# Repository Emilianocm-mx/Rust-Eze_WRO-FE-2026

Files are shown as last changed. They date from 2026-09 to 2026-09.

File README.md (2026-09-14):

## 🤖 Rust-eze — WRO 2026 Future Engineers






Official repository of team **Rust-eze** for the WRO 2026 Future Engineers category. Here you will find the source code of our robot, technical documentation, hardware schematics, and multimedia material from our autonomous robot.

---

## 📑 Table of contents

* [👥 Team](#team)
* [📷 Vehicle Photos](#vehicle-photos)
* [⚙️ Mechanical Process](#mechanical)
* [⚡ Electrical System](#electrical)
* [🔋 Power Budget](#Power-Budget)
* [🔌 Wiring Diagram](#wiring)
* [🛠️ Components](#components)
* [💻 Source Code](#source-code)
* [🔧 Build & Setup](#build)
* [💰 Components Cost](#Components-Cost)
* [👕 Team Photos](#team-photos)

---

## 👥 Team

| Name | Role |
|---|---|
| Emi | Mechanical |
| Oliver | Electronics |
| Paco | Programmer |
| Leo | Coach |

---

## 📷 Vehicle Photos

| Front | Front-2 | Right |
|:---:|:---:|:---:|
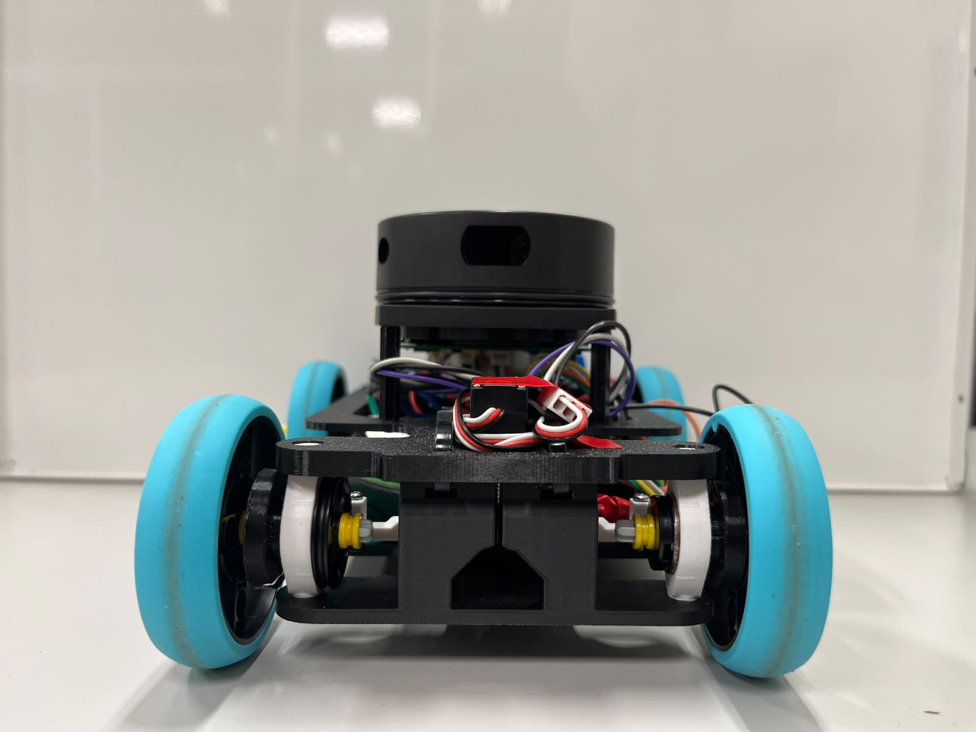
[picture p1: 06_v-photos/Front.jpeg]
Front
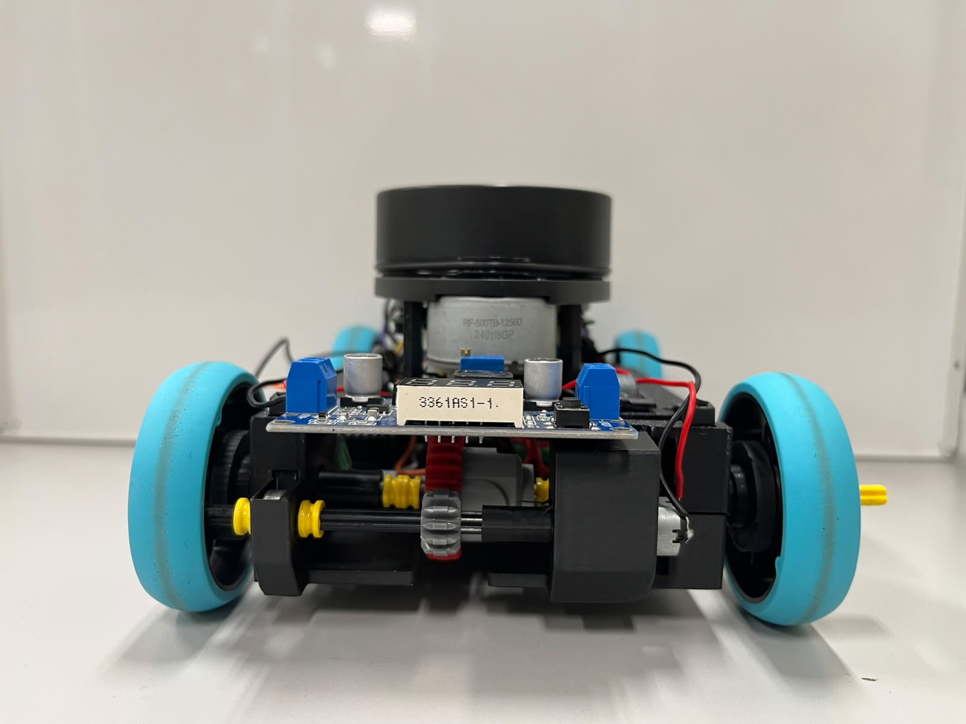
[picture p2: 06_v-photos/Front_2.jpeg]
Front_2
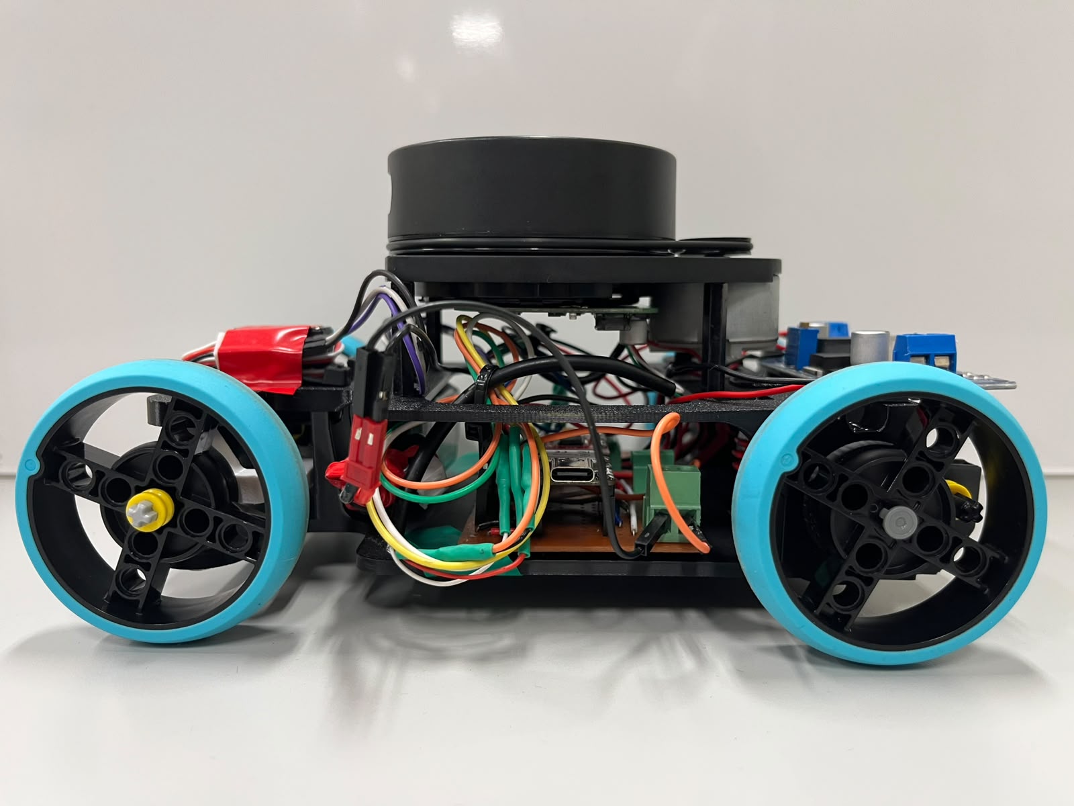
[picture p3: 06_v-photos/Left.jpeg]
Left
|  |  |  |
| **Right-2** | **Top** | **Isometric** |
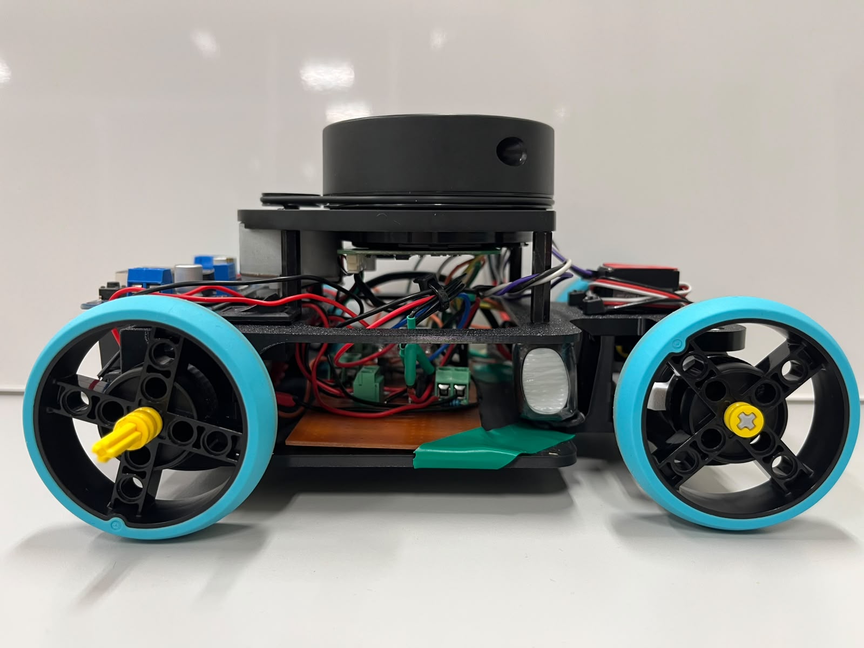
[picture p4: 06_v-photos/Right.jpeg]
Right
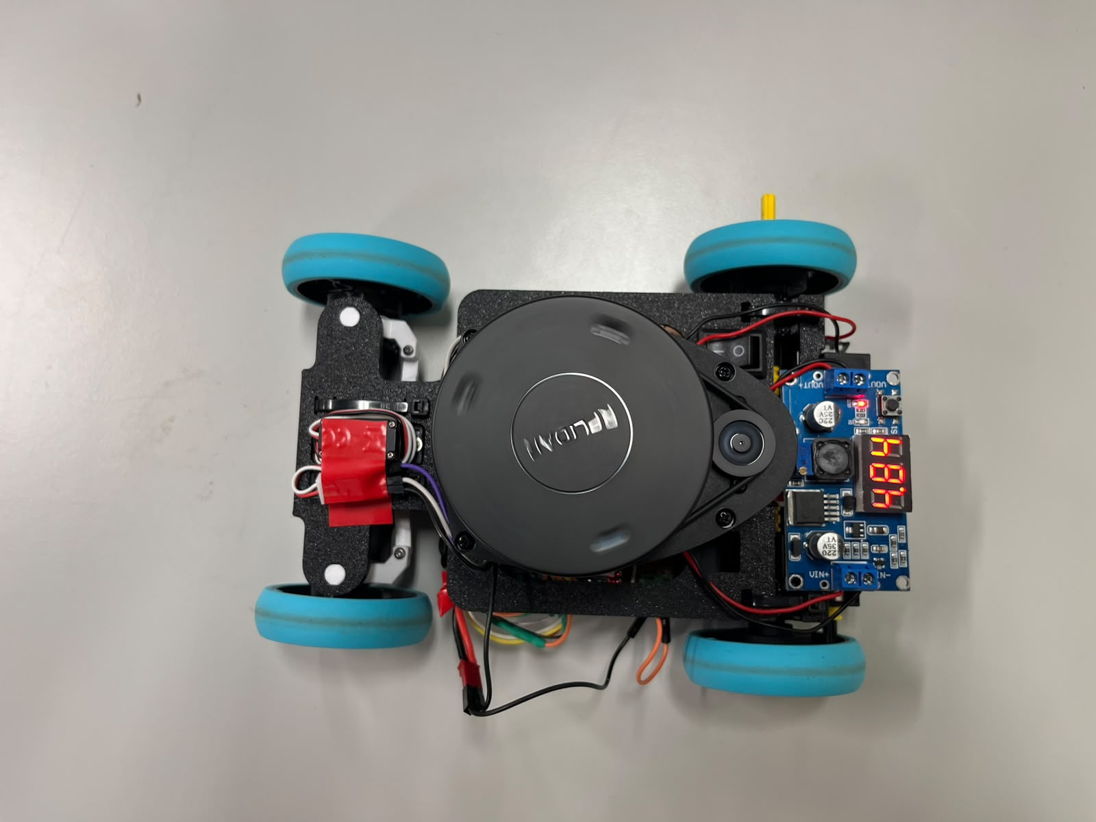
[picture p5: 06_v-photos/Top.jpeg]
Top
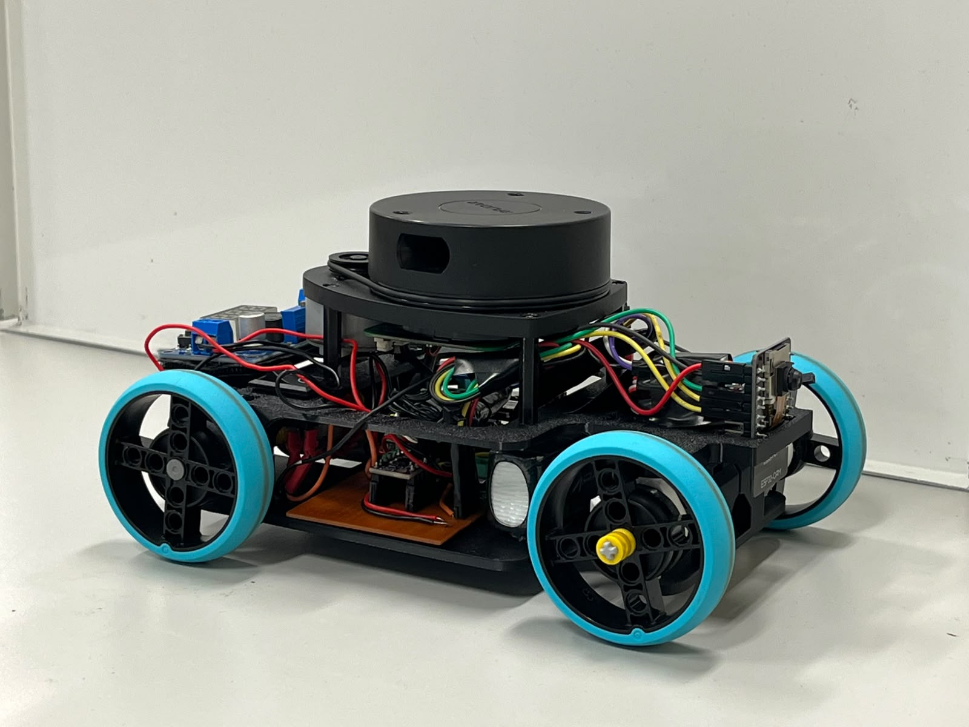
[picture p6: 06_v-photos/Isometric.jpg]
Isometric
|  |  |  |

---

## ⚙️ Mechanical Process

Our mechanical design focuses on stability, and precise maneuverability to tackle the high-speed requirements of the WRO Future Engineers challenges. The entire robot was designed from scratch using CAD software and manufactured via 3D printing. We used SolidWorks as our CAD software:

assy

### 1. Chassis & Weight Distribution
* **Material:** Printed in PLA/PETG for a great balance between rigidity and lightweight performance.
* **Low Center of Gravity:** Heavier components, such as the LiPo battery and the Pololu motor, are mounted as low as possible to prevent the robot from tipping over during sharp corners.
* **Modular Design:** The chassis is divided into easily replaceable sections (front steering assembly, main body, and rear drivetrain) to allow quick repairs during competition days. Also, our CAD desing is basically 2 pieces that consist of a top_cover and main_chassis with each mechanisism working independently.

| Top | Chassis |
|:---:|:---:|
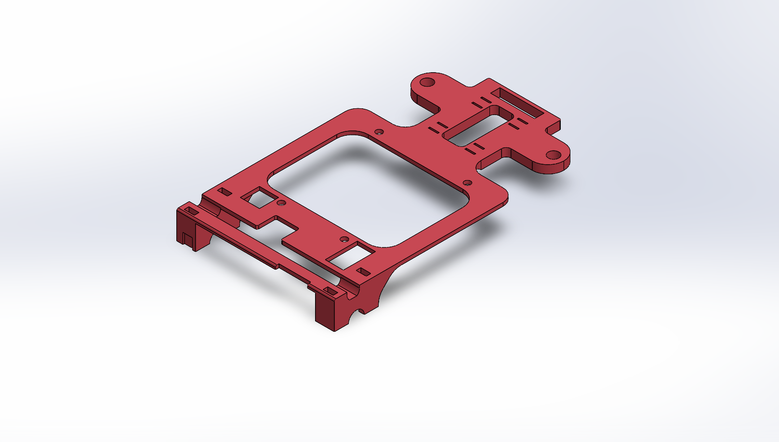
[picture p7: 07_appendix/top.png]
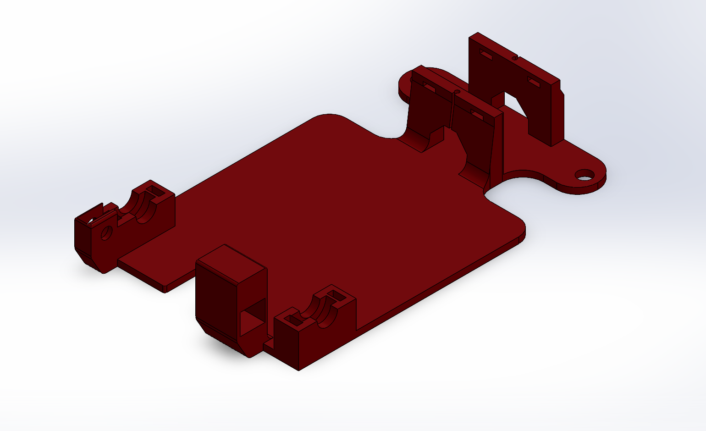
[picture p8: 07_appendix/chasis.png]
|  |  |

### 2. Steering System (Ackermann Geometry)
We used to have a simple paralel steering in our robot, but as we continued with our tests it was clear that the addition of a different type of steering was necessary. To ensure smooth cornering and minimize tire scrubbing, we implemented an **Ackermann steering mechanism** which is the same type that comercial cars use.
* Actuated by the **MG90 Micro Servo** and a steering system assembled with 3 M2 screws ensure that our ackermann the type steering can work efficiently at all times.
* This geometry is critical for maintaining traction and speed while navigating the tight turns of the challenge in general.

| Our Steering | Ackermann Steering Formula |
|:---:|:---:|
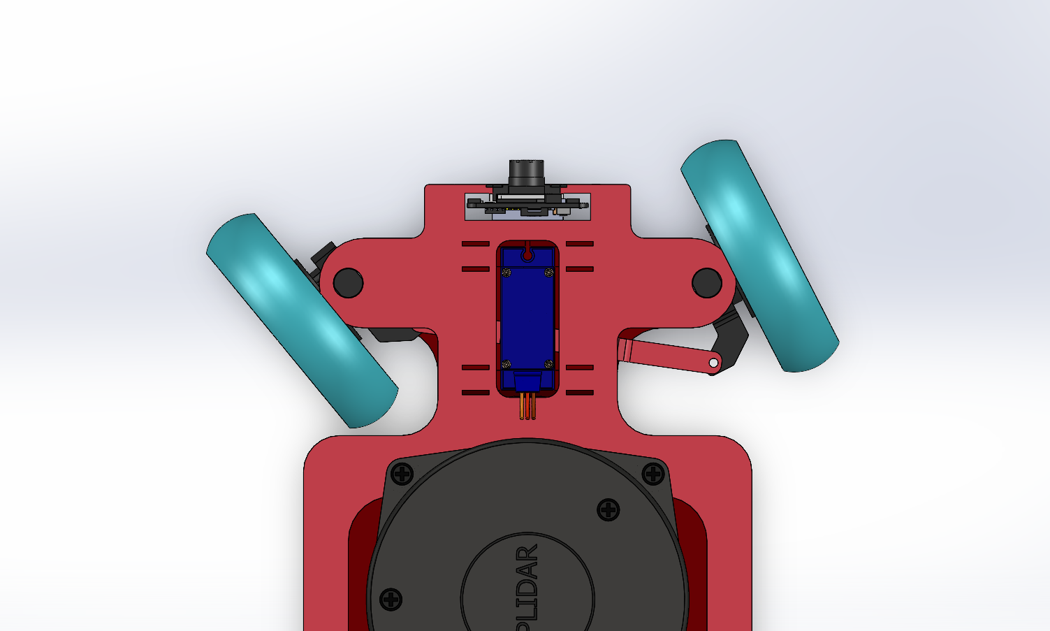
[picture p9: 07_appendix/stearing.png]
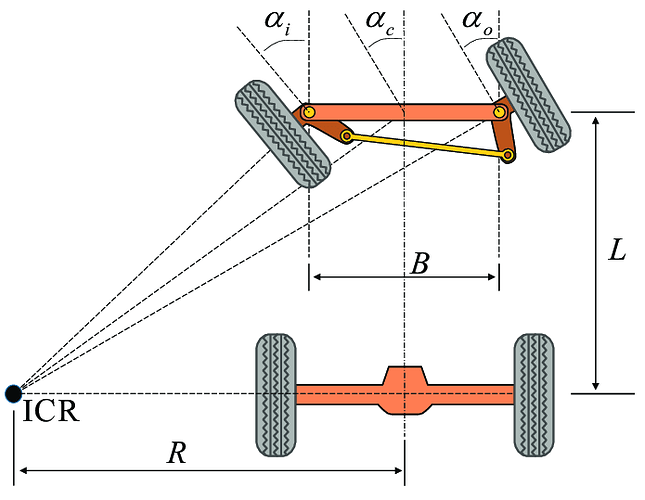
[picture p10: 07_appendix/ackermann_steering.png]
|  |  |

### 3. Drivetrain & Transmission
* **Rear-Wheel Drive (RWD):** Driven by a single **N20 Pololu 300 RPM DC Motor**. While it was not the fist motor we used, the different design itterations helped us find the perfect motor to power out robot. 
* **Power Transfer:** We designed a custom structure with bearings in order to use the lego differential (pieces 65413 and 65414) connecting the motor to the solid rear axle. Originally, the power transfer depended on two single gears of lego (32269 and 32270 being the second one the driver gear), however, this meant a lack of smooth cornering which led us to our new configuration. Our gear ratio was calculated to provide the perfect balance between top speed on the straightaways and high torque for the Obstacle Challenge maneuvers (like parallel parking or the obstacle avoidance). Finally, the design continued to be a mix of 3D printed parts with lego pieces due to the risks that a 3D printed one could have, and since we did not consider necessary to print in stronger materials (like abs or nylon) the legos were a perfect solution to us.

##Transmission & Gear Ratio

| Parameter | Specification |
|---|---|
| Driver gear | 12T |
| Driven gear | 28T |
| **Total Gear Ratio** | **2.33:1** |

For every full rotation of the motor shaft, the differential input rotates 0.43 times. The LEGO new-generation differential distributes torque between both rear wheels with a 1:1 ratio in straight-line motion. During turns, it allows the wheels to rotate at different speeds independently, eliminating tire scrubbing.

** Our torque & performance choices**
* **Mechanical Advantage:** The 2.33:1 gear reduction via the LEGO differential provides adequate torque multiplication for the robot's weight, especially after removing the RPi and powerbank.
* **Overvolting for Performance:** Operating the N20 at 7.4V instead of its 6V nominal rating provides a ~23% increase in both RPM and torque, which compensates for drivetrain friction losses.
* **Electrical Safety:** The TB6612FNG driver operates well within its safe limits with the N20 motor at 7.4V.
* **Weight Optimization:** Migrating from RPi + powerbank to a standalone ESP32 system is estimated to reduce robot weight by 200–250g, improving torque margin from tight to comfortable.

| CAD | Final build |
|:---:|:---:|
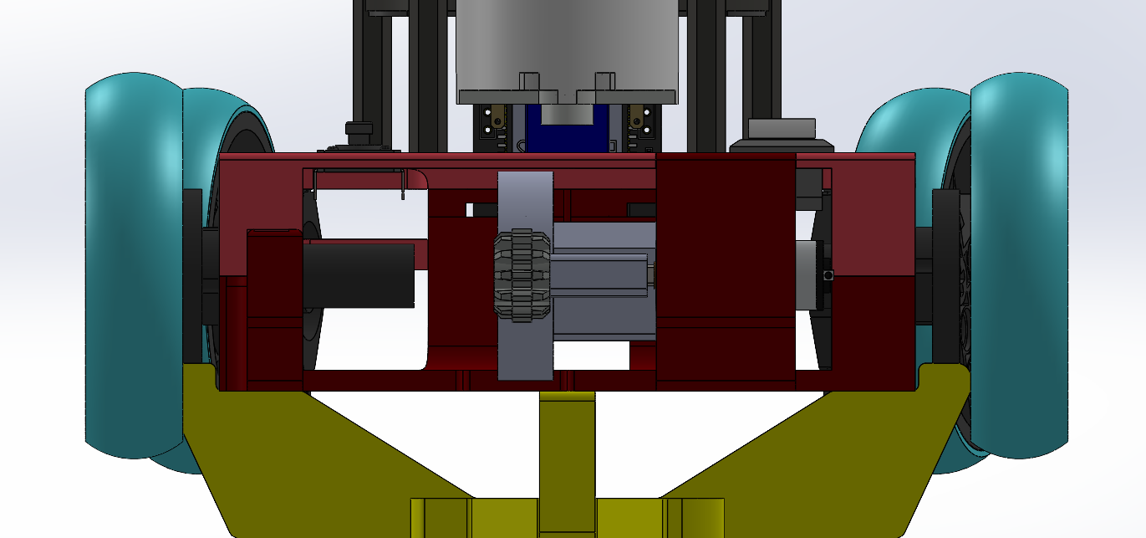
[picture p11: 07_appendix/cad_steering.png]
|  |  |

### 4. Sensor Integration
* **RPLiDAR Tower:** Elevated and centrally mounted to guarantee a 360° unobstructed field of view, preventing any chassis parts from creating blind spots. It is mounted with M2.5 screws with perfectly designed holes in the cassis. It was hard to land with a design that could allow us to fit the electronics without compromising our lidar. Fortunately, the design choice of having to modular pieces was a perfect way of attacking this problem without the appearance of further problems regarding this.
* **Camera Mount:** The ESP32-CAM is mounted in front of the robot with a simple slot on the cassis so that it can still be taken out easily without compromising stability. We consider this a perfect example of our design choices, since we did not had to create a whole assembly in order to mount the camera in the chassis.

| Mounting holes | Final build |
|:---:|:---:|
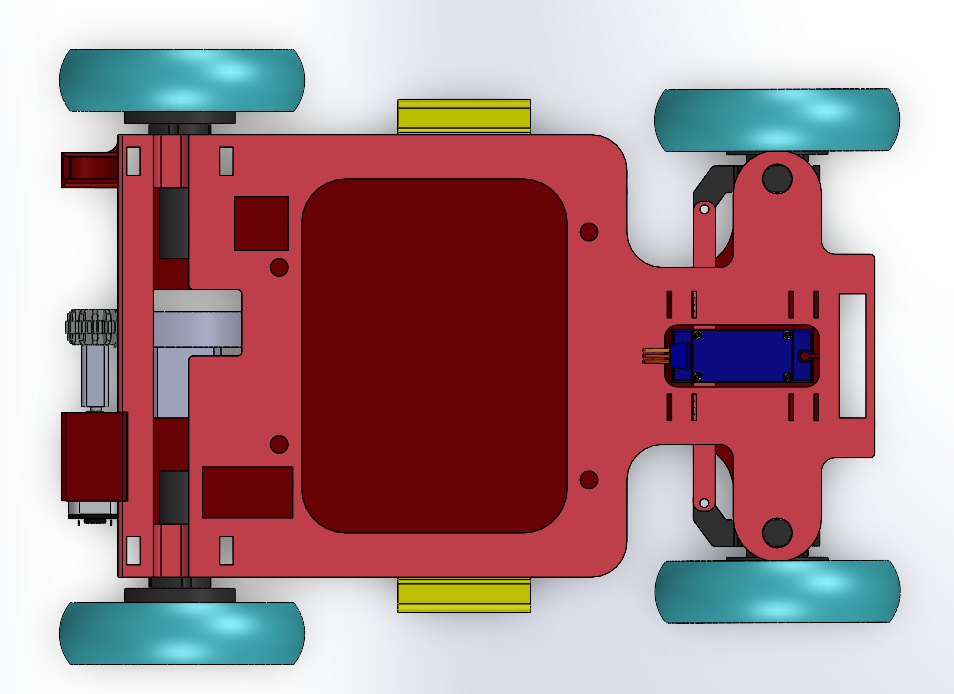
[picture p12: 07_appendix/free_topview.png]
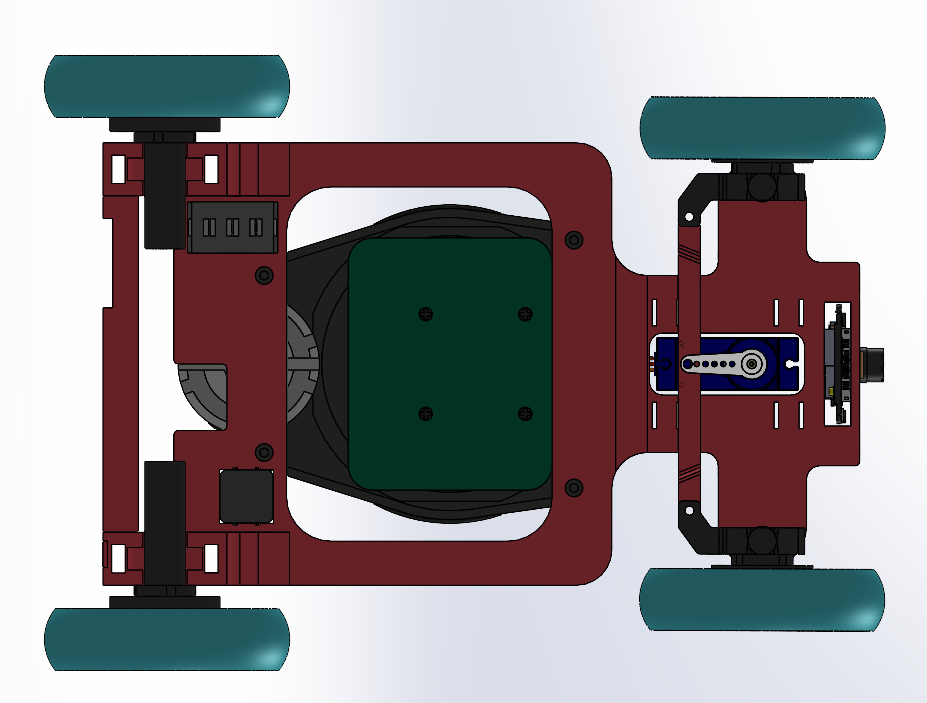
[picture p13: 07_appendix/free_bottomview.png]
|  |  |

### 🔄 Design Iterations

| Version | Focus Area | Key Improvements |
|---|---|---|
| **V1.0** | Functionality and weight reduce | Since we used to depend on a RPI and a PWR BANK, the chassis needed to be light and sturdy in order hold up with the weight of this components. |
| **V2.0** | Steering Optimization | Implemented Ackermann geometry, with a MG90 servo in order to provide more torque for our robot. |
| **V3.0** | Final Frame | We changed to lighter components (XIAO C6 and LiPo battery) so our final chassis ended up being more sturdy and easy to assemble then at the beggining. |

---

## ⚡ Electrical System
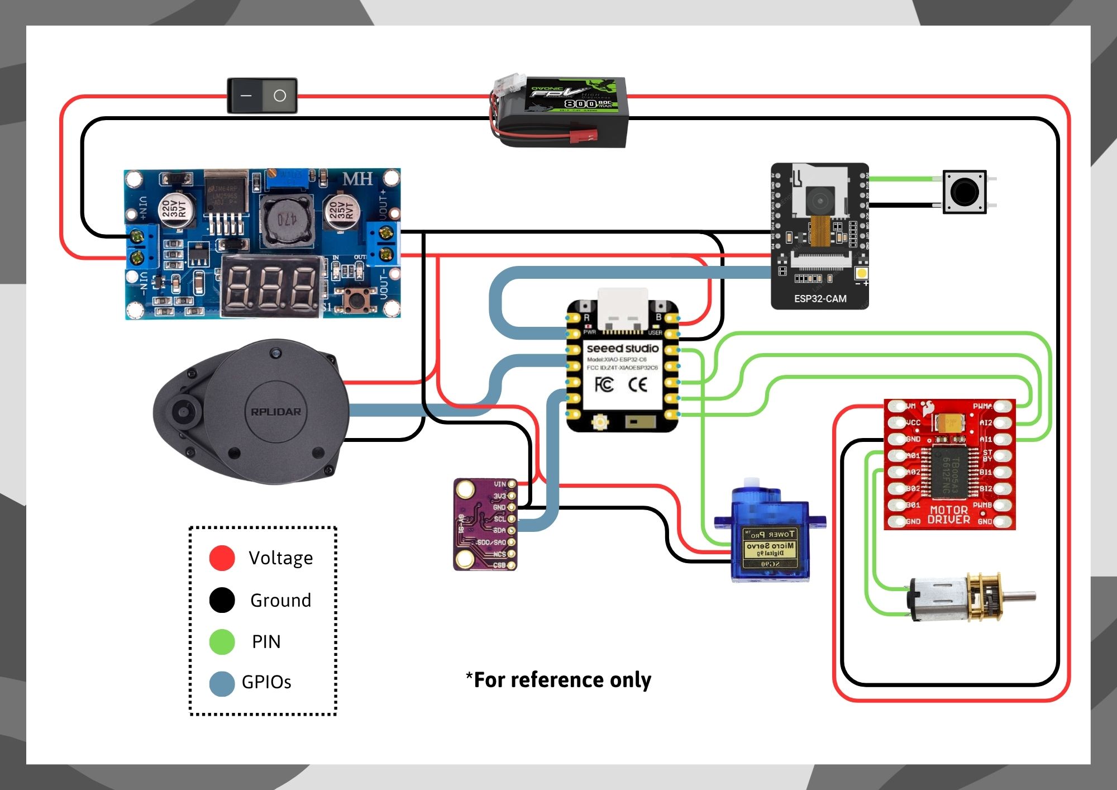
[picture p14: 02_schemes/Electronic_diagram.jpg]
Electronic Scheme


---

### 🔋 Power Budget

The entire vehicle is powered by a 7.4V 800mAh 2S LiPo battery. Power splits into two primary pathways following the main toggle switch (U1): the motor driver takes the 7.4V battery voltage directly to power the DC motor (VM pin), while the rest of the system is fed through an LM2596 step-down converter producing a stable 5V supply at up to 3A.

| Rail | Voltage | Consumers | Estimated Peak Current |
|:---|:---:|:---|:---:|
| Main Power Rail | 7.4V (2S LiPo) | Total system power distribution through Switch (U1) | ~1.85 A |
| 5V Regulated Rail | 5V | LM2596 Converter output -> XIAO ESP32-C6, ESP32-CAM, RPLiDAR A1M8, MG90 Micro Servo, TB6612FNG (VCC logic) | ~1.30 A |
| 7.4V Motor Rail | 7.4V | TB6612FNG Driver (VM) -> Pololu DC Motor (N20) | ~0.50 A |
| 3.3V Logic Rail | 3.3V | GY-BMI160 (IMU) & Push-Button (fed via XIAO ESP32-C6 internal 3.3V regulator) | ~50 mA |

### Battery Selection & Justification

* **Voltage Compatibility:** The 7.4V (2S LiPo) nominal voltage provides optimal operating voltage for the Pololu DC motor without needing a boost converter, while offering enough voltage overhead for the LM2596 buck converter to cleanly step down to 5V.
* **Separation of Power Paths:** Feeding 7.4V directly to the TB6612FNG motor driver (VM) isolates motor stall-current spikes and noise from the 5V logic rail. This prevents brownouts and reboots on the XIAO ESP32-C6, ESP32-CAM, and RPLiDAR A1M8 during sudden motor acceleration.
* **Discharge Headroom:** Standard 800mAh 2S LiPo batteries feature continuous discharge ratings of at least 20C (16 A continuous output). With a total system peak draw of ~1.85 A, the vehicle draws under 12% of the battery's maximum discharge capability, protecting the cells from overheating and voltage drop.
* **Weight & Operating Time:** At a typical average draw of 600–800 mA during autonomous navigation, the 800mAh capacity provides around 45 to 60 minutes of runtime while maintaining a low overall vehicle mass.

---

## 🔌 Wiring Diagram
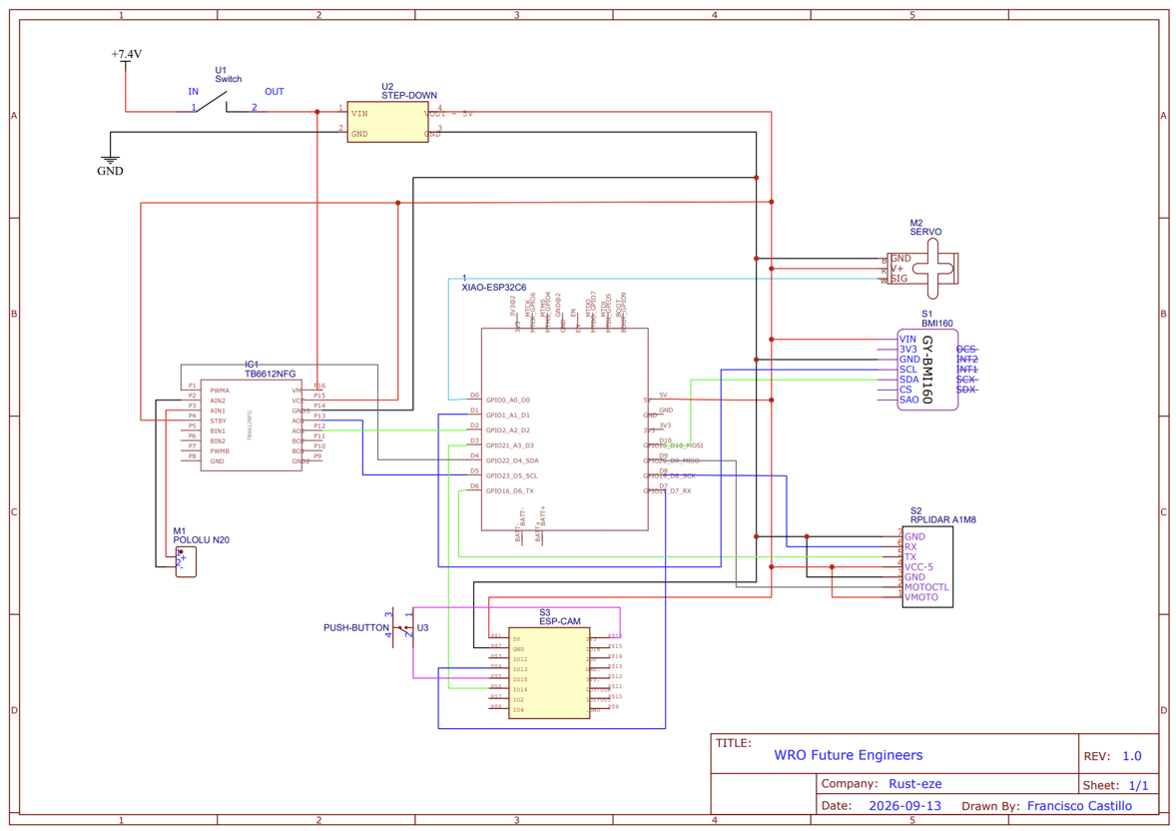
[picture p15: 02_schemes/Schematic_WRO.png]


### Pin Reference

| Component | ESP32-C6 Pin | Function |
|---|---|---|
| LiDAR RX | GPIO 19 | UART data from LiDAR |
| LiDAR TX | GPIO 16 | UART data to LiDAR |
| LiDAR motor | GPIO 20 | PWM speed control |
| Servo MG90 | GPIO 0 | Steering PWM |
| Motor PWMA | GPIO 22 | Drive motor speed |
| Motor AIN1 | GPIO 23 | Drive motor direction A |
| Motor AIN2 | GPIO 2 | Drive motor direction B |
| ESP32-CAM RX | GPIO 21 | UART from camera |
| ESP32-CAM TX | GPIO 17 | UART to camera |
| IMU SDA | GPIO 18 | I2C data (BMI160) |
| IMU SCL | GPIO 1 | I2C clock (BMI160) |

---

## 🛠️ Components

| Photo | Component | Description |
|:---:|---|---|
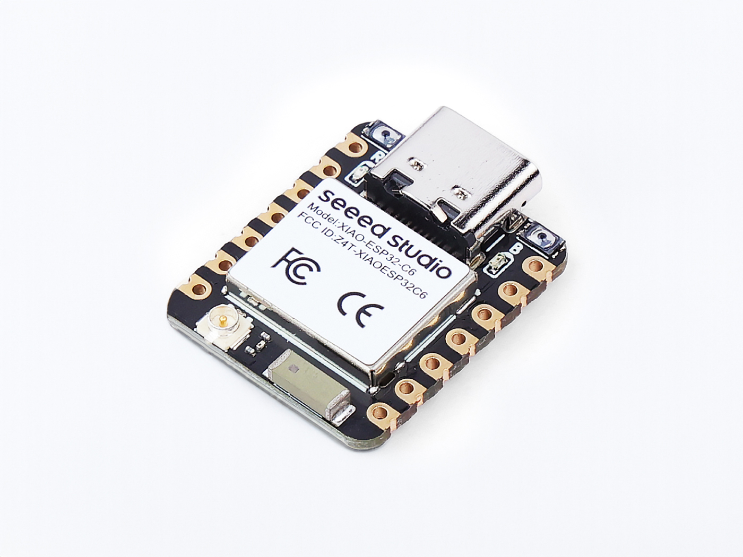
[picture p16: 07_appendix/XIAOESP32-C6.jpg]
|  | **XIAO ESP32-C6** | • Main microcontroller of the robot <br> • Processes RPLiDAR distance data <br> • Controls steering servo and motor driver <br> • Communicates with ESP32-CAM via UART <br> • Runs navigation and PID control logic |
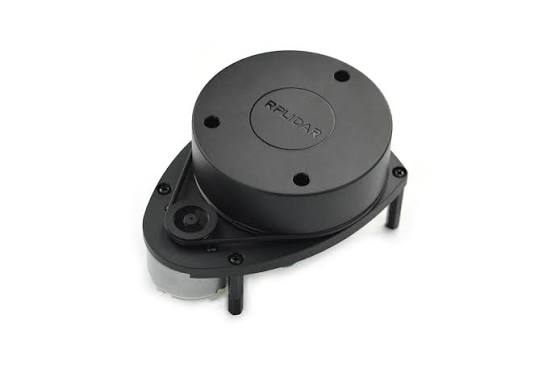
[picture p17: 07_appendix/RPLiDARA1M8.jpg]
|  | **RPLiDAR A1M8** | • 360° laser distance scanner <br> • Primary perception sensor for wall following <br> • Detects corners, open spaces and obstacles <br> • Connected to ESP32-C6 via UART (TX/RX) <br> • Powered at 5V from LM2596 |
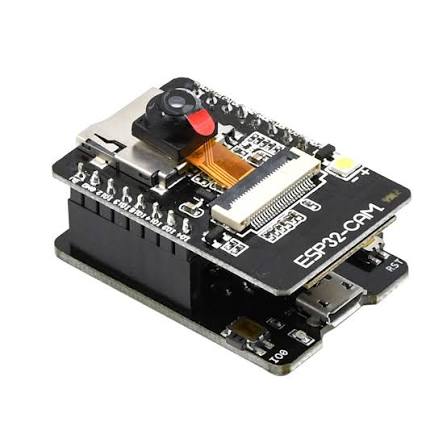
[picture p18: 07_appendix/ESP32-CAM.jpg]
|  | **ESP32-CAM** | • Handles visual color detection <br> • Identifies red and green traffic sign pillars <br> • Sends color decisions to ESP32-C6 via UART <br> • Used to initialize the code with the button |
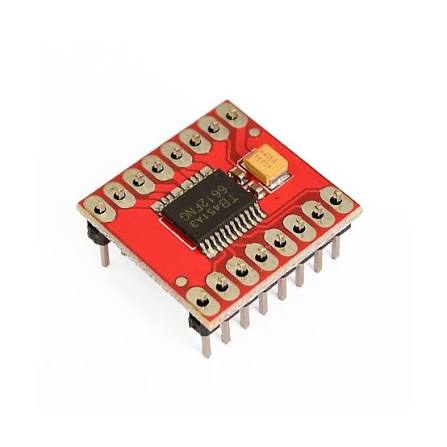
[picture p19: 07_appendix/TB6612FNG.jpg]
|  | **TB6612FNG Motor Driver** | • Controls Pololu DC motor speed and direction <br> • Accepts PWM + direction signals from ESP32-C6 <br> • Powered directly from LiPo at 7.4V <br> • Protects ESP32 from motor current draw |
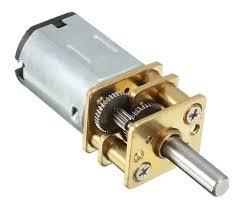
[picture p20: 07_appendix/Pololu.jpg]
|  | **Pololu DC Motor 300 RPM** | • Rear-wheel drive traction motor <br> • Connected to rear axle through physical gear system <br> • Speed controlled via PWM through TB6612FNG <br> • Single motor drives both rear wheels |
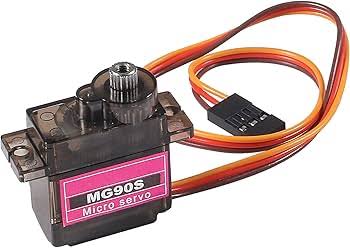
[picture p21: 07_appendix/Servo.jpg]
|  | **MG90 Micro Servo** | • Controls front steering mechanism <br> • Physical range: 40° (full left) to 140° (full right) <br> • Center position at 90° = straight ahead <br> • PWM signal from ESP32-C6 GPIO 0 |
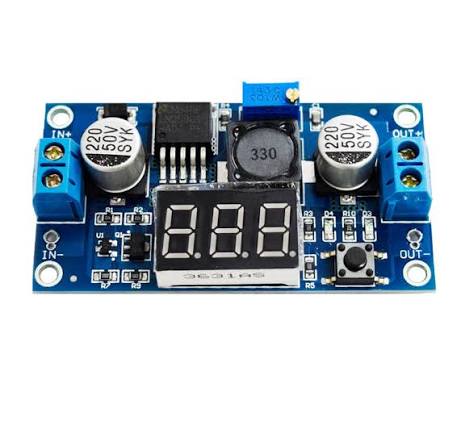
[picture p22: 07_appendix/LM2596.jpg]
|  | **LM2596 Step-Down Regulator** | • Converts 7.4V LiPo down to stable 5V <br> • Powers all logic components safely <br> • Prevents voltage damage to ESP32 and LiDAR <br> • Adjustable output verified before use |
|  | **LiPo Battery 7.4V 800mAh** | • Main power source for the entire system <br> • Directly feeds motor driver at full voltage <br> • Feeds LM2596 for 5V logic rail <br> • Lightweight for weight-sensitive robot design |
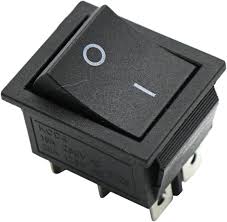
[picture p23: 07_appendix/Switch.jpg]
|  | **Power Switch** | • Master on/off switch for the entire system <br> • Required by WRO rules (one switch to power on) <br> • Cuts all power from battery before start |
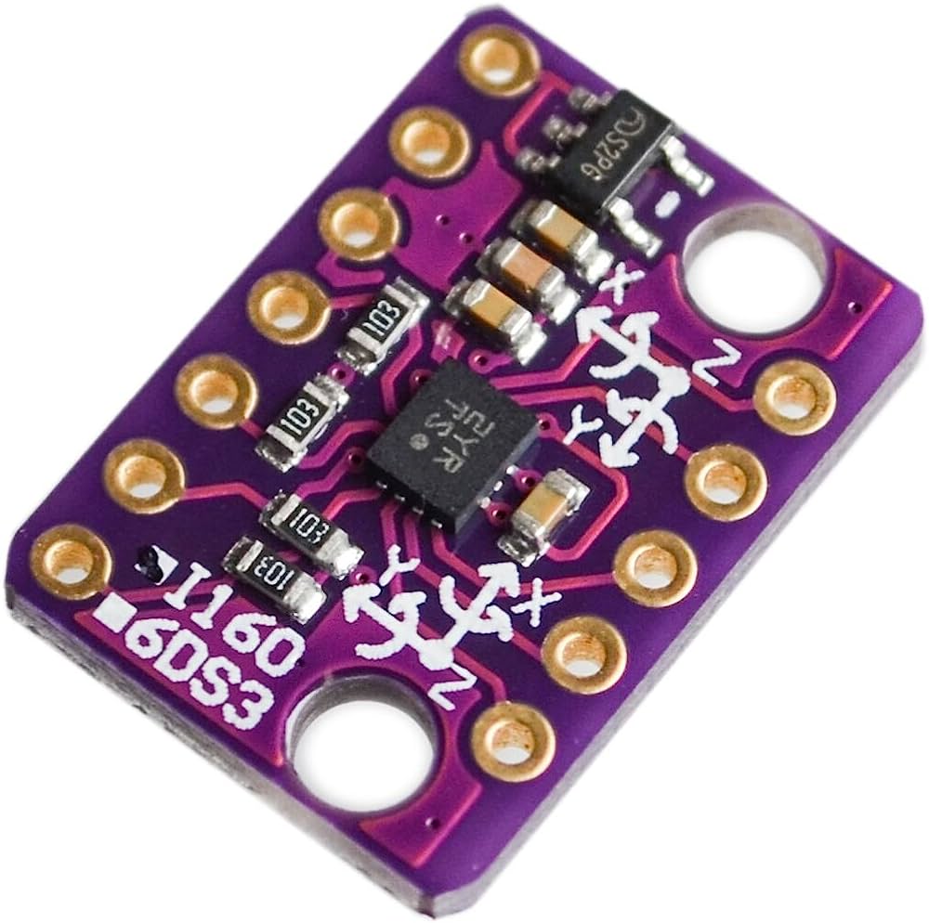
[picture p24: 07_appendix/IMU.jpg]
|  | **BMI160** | • Inertial measurement unit <br> • Provides heading and orientation data <br> • Supports navigation during turns <br> • Connected via I2C (SDA/SCL) to ESP32-C6 |

---

## 💻 Source Code

The main program runs on the **XIAO ESP32-C6**, which processes RPLiDAR distance data in real time, fuses it with IMU heading data, and controls both the steering servo and drive motor through a hybrid PID + yaw control system.

We would like to include more images but since the lidar does not map due to the way our code works the only images that we can provide come from the esp-cam.

---

### System Capabilities

- Reads 360° distance data from the RPLiDAR A1M8 via UART, sampling specific angles as named rays (0°, 60°, 90°, 120°, 170°, 180°, 190°, 240°, 270°, 300°, 340°, 20°)
- Integrates gyroscope data from the BMI160 at 100 Hz to track heading (yaw) with automatic bias calibration at startup
- Runs a **hybrid steering controller**: IMU-based yaw control as primary, with LiDAR wall-following as fallback when IMU is invalid
- Maintains a dynamic wall distance setpoint that is captured fresh after each corner, adapting to each corridor without forcing a fixed target
- Detects corners using a multi-condition state machine: front wall blocked + back clear + lateral opening confirmed + opposite wall closed
- Counts completed corners and laps, stopping the motor autonomously after 3 laps (12 corners total)
- Applies **IMU drift correction** continuously during straight sections by comparing wall angle against integrated yaw
- Receives red/green pillar color data from ESP32-CAM via UART with CRC-validated framing (Obstacle Challenge)
- Implements a **two-device start protocol**: the robot waits for a button press signal from the ESP32-CAM before enabling motion, satisfying WRO's one-button start rule without a physical button on the main controller

---

### 🏁 Open Challenge

The Open Challenge uses the RPLiDAR as the primary perception source and the BMI160 as the heading reference. No camera input is used.

**Startup sequence:**
The robot initializes the BMI160, collects 500 gyroscope samples to compute a Z-axis bias offset, then starts the LiDAR and waits for the start signal from the ESP32-CAM button. Once received, it waits 500 ms before enabling motion, giving the LiDAR rotor time to reach full speed and the IMU reference to settle.

**First corridor:**
Before the first corner is completed, `trackDir` is `UNKNOWN`. The robot reads two diagonal rays on each side (60°/120° for right, 300°/240° for left) and selects whichever wall is closer as its reference. It then follows that wall at the measured distance, using parallelism between the front and back rays to stay aligned. A soft-escape maneuver activates if the robot starts too close to a wall, gently steering away until a safe clearance is reached.

**Straight-line control:**
Once a reference wall is selected, the steering loop runs every 20 ms. It computes a desired yaw correction from the wall distance error, rate-limits the setpoint change to avoid sharp inputs, then feeds it into a yaw P+D controller using the IMU. The derivative term damps oscillation using the live gyroscope rate rather than a numerical derivative. While the IMU is valid, this loop runs as primary. If the IMU fails or loses calibration, the system falls back to a pure LiDAR PID on the wall rays directly.

**Drift correction:**
On every straight section, the system compares the geometric angle of the tracked wall (computed from the two diagonal rays) against the IMU's relative yaw. If they differ consistently, a slow integrating correction is applied to `yawOffset`, keeping the IMU reference aligned with reality over time without introducing sudden jumps.

**Corner detection:**
A corner is triggered when all of the following are true simultaneously: a front wall is detected below 1200 mm, the back is clear beyond 1500 mm, the lateral opening on the turn side has been continuously open for at least 100 ms after previously seeing a wall, and the opposite wall confirms a corridor is closed. This multi-condition approach prevents false triggers from partial LiDAR returns or transient reflections.

**Turn execution:**
When a corner is confirmed, the servo goes to full lock and the IMU target is updated by ±90°. The turn completes when the IMU error falls within 4° and the angular rate drops below 35°/s for 60 ms. A 1400 ms timeout serves as a safety fallback. After the turn, the wall distance setpoint is re-captured from the new corridor's diagonal rays, and all PID state (integral, error smoother) is reset to avoid impulse artifacts.

**Lap completion:**
After 12 corners (3 laps × 4 corners), the robot enters `FINAL_APPROACH` state, drives forward for a calibrated time window (currently 800 ms), then cuts the motor and centers the servo, stopping autonomously in the finish section.

---

### 🚧 Obstacle Challenge

🚧 Obstacle Challenge
The Obstacle Challenge software relies on a tightly coupled sensor fusion architecture running on the XIAO ESP32-C6. Rather than executing hardcoded routines, the robot operates on a reactive state machine that dynamically calculates trajectories based on real-time LiDAR point clouds, IMU gyroscope integration, and ESP32-CAM visual data.

| Red obstacle | Green obstacle |
|:---:|:---:|
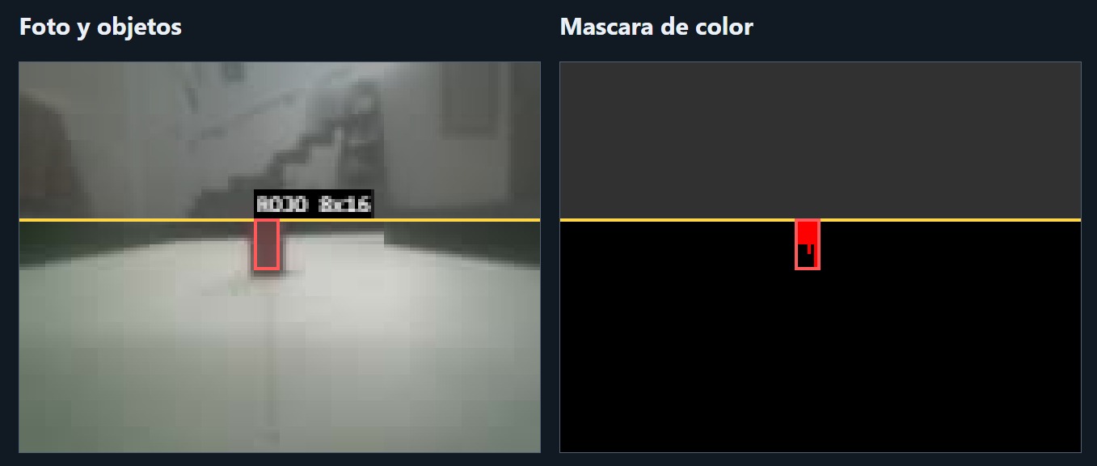
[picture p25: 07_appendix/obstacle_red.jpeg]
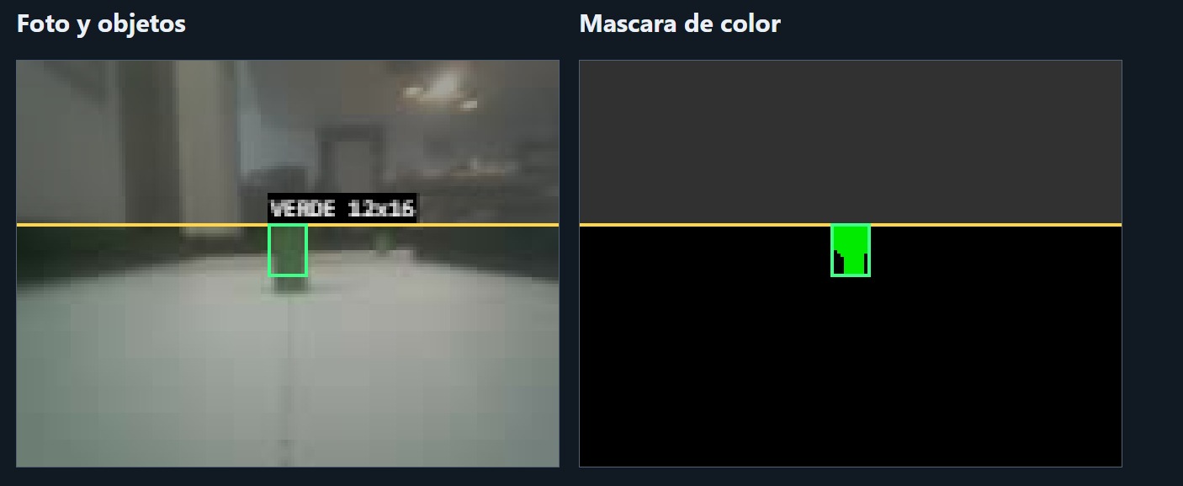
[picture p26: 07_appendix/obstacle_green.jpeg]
|  |  |

**Vision-to-LiDAR Spatial Mapping:** The ESP32-CAM processes frames and transmits color (Red/Green) and bounding box data via a CRC16-validated UART protocol. Because a 2D camera cannot measure depth accurately, the C6 calculates the visual bearing of the bounding box (imageAngle) and feeds it into the findPillar() function. This function scans the 360° RPLiDAR array at that specific angle to extract the exact physical distance and width of the pillar.

**Dynamic Evasion (maneuverHeading & adaptPassToWall):** Once a pillar is mapped, the robot determines the passing side (Red = right, Green = left). It calculates a plannedOffset by measuring the available space between the pillar and the lane walls (laneWallDistance). The maneuverHeading function then generates a target yaw angle to steer the robot smoothly around the obstacle without hitting the perimeter walls.

**Corner Detection & Reversing Maneuvers:** Instead of relying on a single distance threshold, fitCornerWall() uses a mathematical line-fitting algorithm to analyze multiple LiDAR points and confirm a flat wall is ahead. Combined with sampleCornerEvidence()—which verifies the front is blocked, the right is open, and the left is closed—the robot initiates a precise IMU-guided turn (REVERSING_TURN), applying reverse motor thrust if clearance (FRONT_CHASSIS_GAP_MM) drops too low.

**State Machine & Fault Recovery (serviceRecovery)**: The robot cycles through states like MOVING, PARALLEL, and CENTERING. If sensor data drops (e.g., LiDAR UART lag or missing camera frames), the robot instantly enters a RECOVERING state, cutting motor power (ESPERA_DATOS) until stable readings return, preventing blind crashes.

Development Evolution & Our Technical Challenges

**Camera Processing Latency:** Early versions of the code suffered from "ghost pillars." By the time the ESP32-CAM finished processing a frame and sent it to the C6, the robot had already moved and rotated, making the camera's angle data obsolete. We solved this by recording the IMU's exact heading (photoYaw) the millisecond a photo is requested, allowing the C6 to mathematically offset the camera's bearing by the exact amount the robot turned during the processing delay.

**LiDAR Noise and False Corners:** The RPLiDAR (Or at least our model - A1M8) occasionally returns fragmented points or is unnable to detect the walls after certain distances do to the black matte color we chose as painting, triggering false corners or simply not giving back any data. We evolved the code from basic distance thresholds to the current CornerEvidence system, which requires simultaneous confirmation of a solid front wall (via line-fitting), an open side passage, and an opposite solid wall before committing to a turn.

**Serial Communication Bottlenecks:** Managing two high-speed UART streams (LiDAR at 115200 baud, Camera at 38400 baud) alongside I2C IMU reads caused buffer overflows and corrupted packets. We implemented a custom LidarStreamReader ring buffer and strict CRC16 checksums for the camera, allowing the system to instantly discard corrupted bytes without crashing the main loop.

---

## 🏁 Challenge Summary

| Feature | Open Challenge | Obstacle Challenge |
|---|---|---|
| Laps | 3 | 3 |
| Traffic signs | - | ✓ Red & Green pillars |
| Parking | - | ✓ Parallel parking |
| Primary sensor | RPLiDAR | RPLiDAR + ESP32-CAM |

---

## 🔧 Build & Setup

### 1. 🖨️ Print the chassis
Download the 3D models from the `01_models/` folder and print the required parts. We provided a .STEP model of our 

### 2. ⚙️ Assemble the robot
Mount the motors, servo, LiDAR, and electronics onto the chassis following the design layout. We provided images in order to understand where each component goes.

### 3. 🔌 Wire the electronics
Follow the wiring diagrams we provided at `02_schemes/` to connect all components.

### 4. 💻 Upload the code
Connect each microcontroller to a computer and flash the corresponding programs:
- From `03_src/` → Upload the file named _Open.ino_ to the XIAO ESP32-C6 using Arduino IDE or any other IDE you like.

### 5. 🔋 Power on and test
Connect the LiPo battery cables, flip the power switch, and verify all systems initialize correctly. You can now place the robot on the track and press the button in order to initialize the program you want.

---

## 💰 Components Cost

| ID | Component | Description | Approximate Cost |
|:---:|:---:|:---:|:---:|
| 1 | Top and Chassis | Main structural frame holding all robot components (PETG) | $5 USD |
| 2 | Steering Parts | Mechanical linkages and mounts for wheel direction control (PETG) | $1 USD |
| 3 | LEGO Wheels | Rubber tires and rims providing traction and mobility | $1.5 USD |
| 4 | XIAO ESP32-C6 | Primary microcontroller for overall processing and wireless connectivity | $5 USD |
| 5 | RPLiDAR A1M8 | 360-degree laser scanner for environment mapping and obstacle detection | $100 USD |
| 6 | ESP32-CAM | Microcontroller with integrated camera module for video feed and Wi-Fi | $7 USD |
| 7 | TB6612FNG Motor Driver | Dual H-bridge module for controlling DC motor speed and direction | $5 USD |
| 8 | Pololu DC Motor 300 RPM | High-torque geared motor driving the primary drivetrain wheels | $7 USD |
| 9 | MG90 Micro Servo | Compact actuator responsible for precise steering adjustments | $5 USD |
| 10 | LM2596 Step-Down Regulator | Buck converter reducing battery voltage to stable system levels | $2.5 USD |
| 11 | LiPo Battery 7.4V 800mAh | Rechargeable power source providing high current for electronics and motors | $20 USD |
| 12 | Power Switch | Toggle mechanism for turning system power on and off | $1 USD |
| 13 | BMI160 | 6-axis Inertial Measurement Unit measuring orientation and motion | $4 USD |
| 14 | Button | User input switch for triggering custom code or system reset | $1 USD |
| 15 | Bearing 6x10x3 | Single ball bearing to stabilize the motor shaft and secure its alignment | $1 USD |
| 16 | Bearing 17x9x5 | Ball bearings for the 4 wheels to ensure smooth rotation and low friction | $4 USD |
| | | | TOTAL: $170 USD|

---

## 👕 Team Photos 

| Team | Paco | Emi | Oliver |
|:---:|:---:|:---:|:---:|
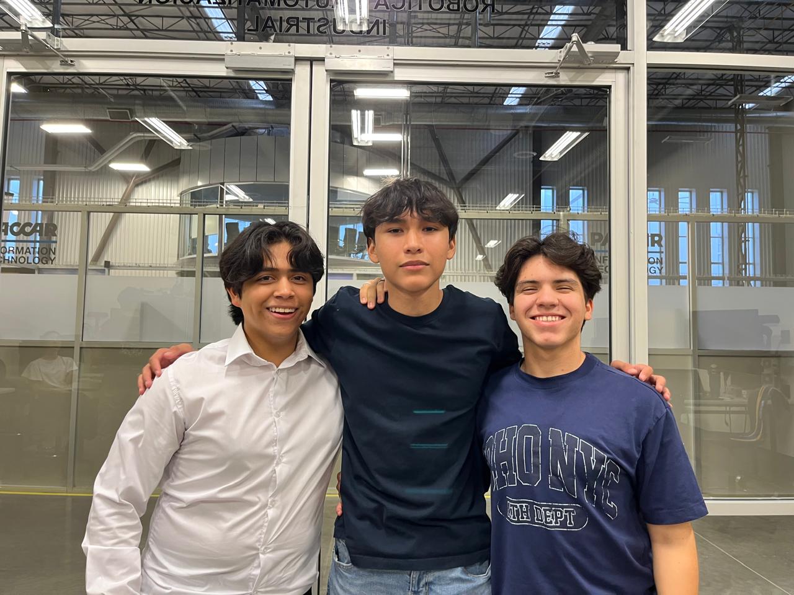
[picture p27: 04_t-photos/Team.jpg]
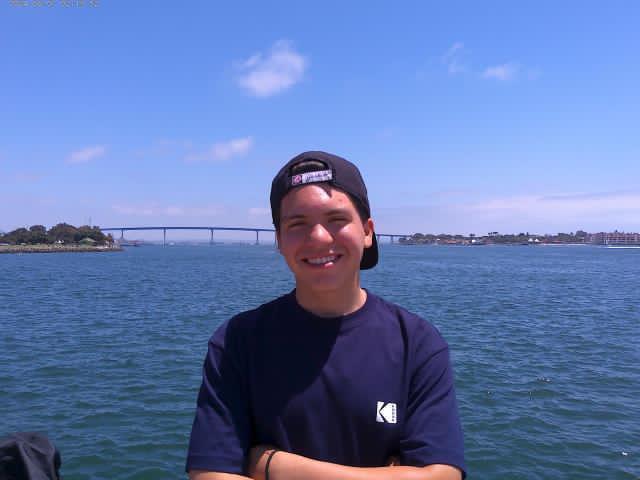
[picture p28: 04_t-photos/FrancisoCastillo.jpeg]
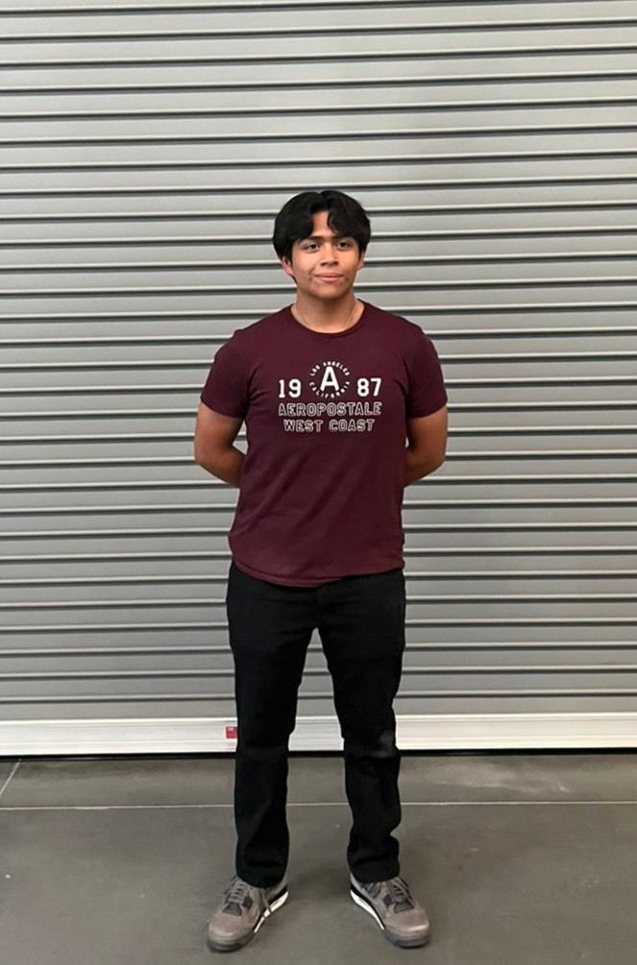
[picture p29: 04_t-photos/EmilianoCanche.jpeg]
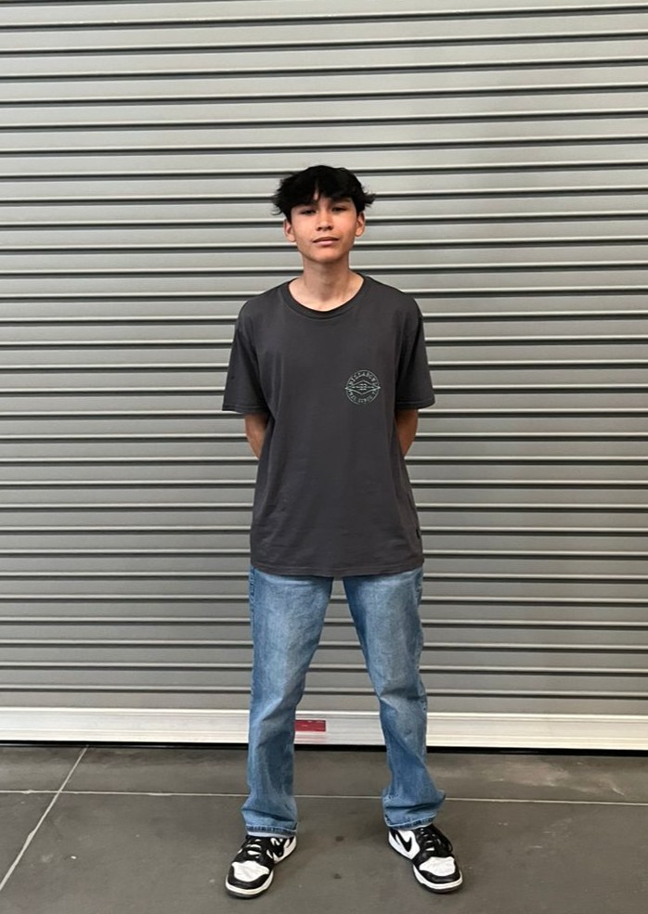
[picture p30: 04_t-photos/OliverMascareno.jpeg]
|  |  |  |  |

---

## 🎬 Videos

| Challenge | Link |
|---|---|
| Open Challenge — No obstacles | [Watch](05_video/WRO_Open_Challenge.mp4) |
| Obstacle Challenge |  -----  |
---
- [Go to top](#-rust-eze--wro-2026-future-engineers)

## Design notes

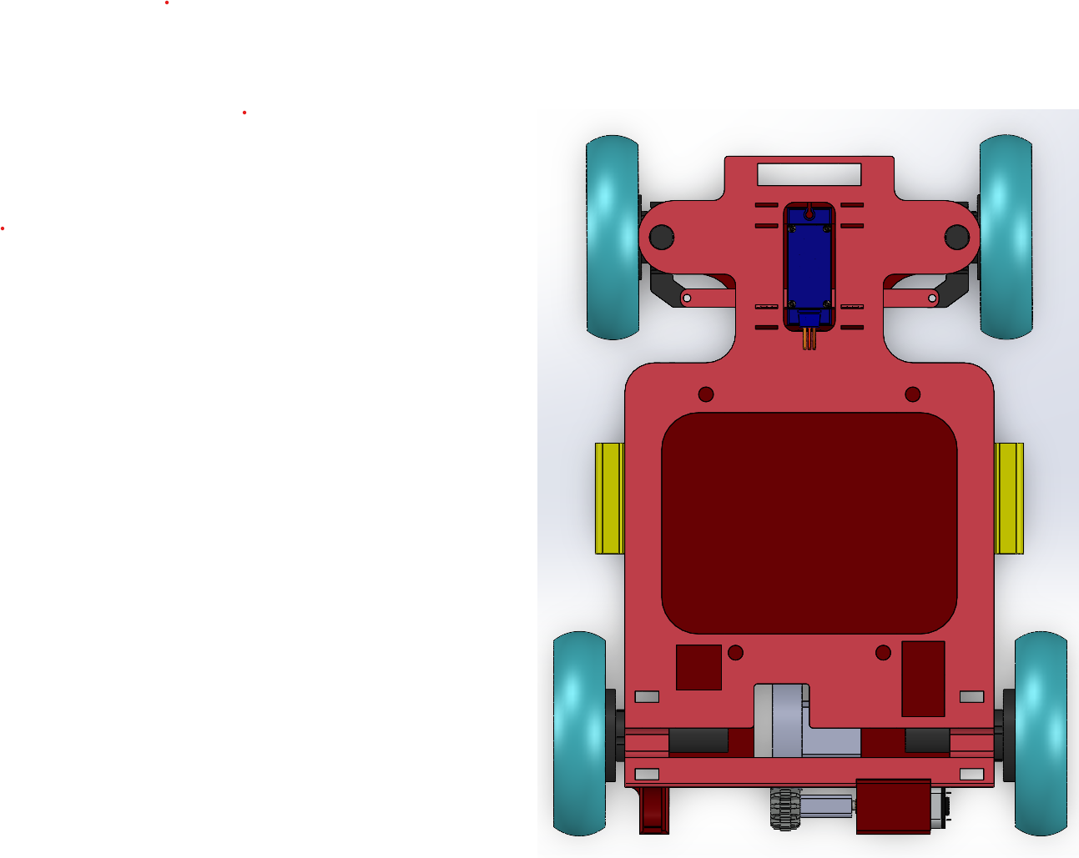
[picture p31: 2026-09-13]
07_appendix/blank_top_view.png

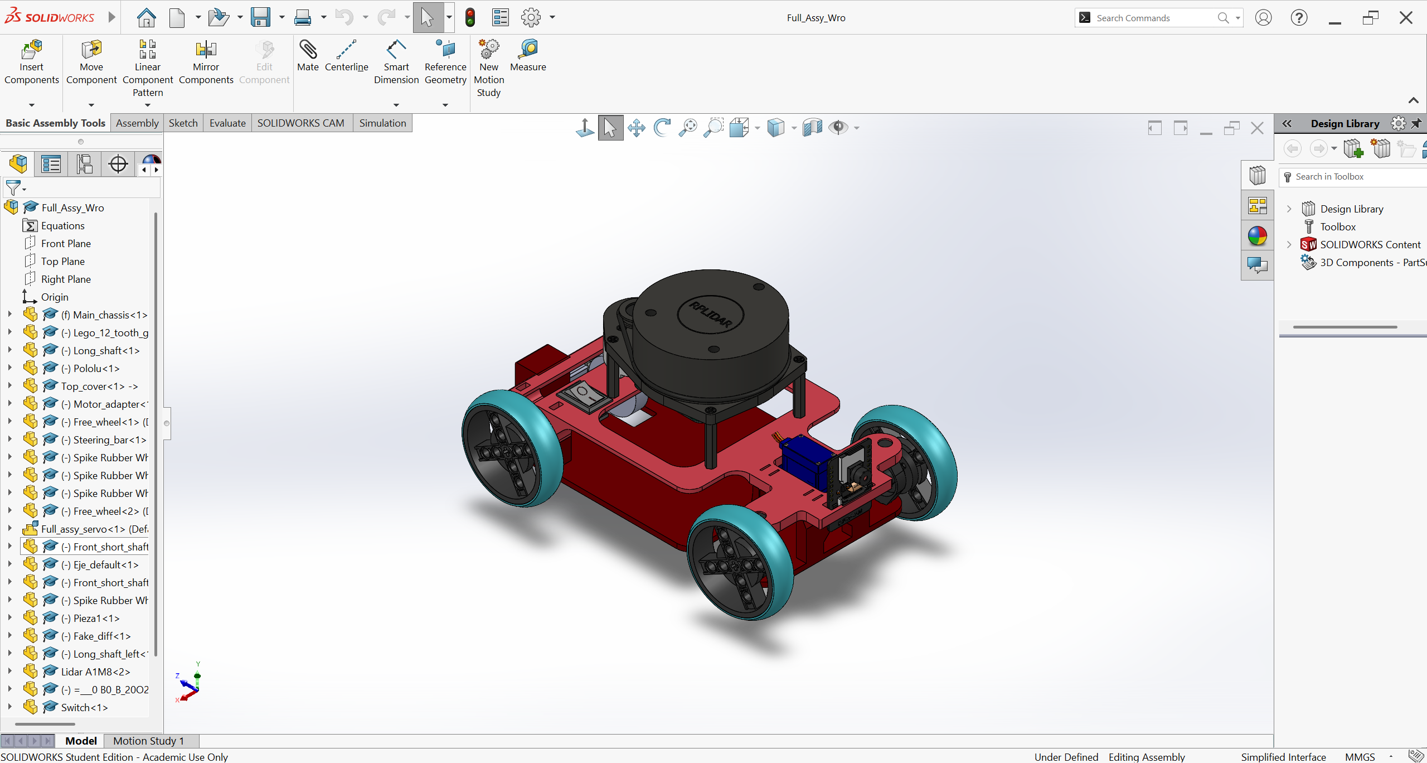
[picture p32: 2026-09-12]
07_appendix/assy.png

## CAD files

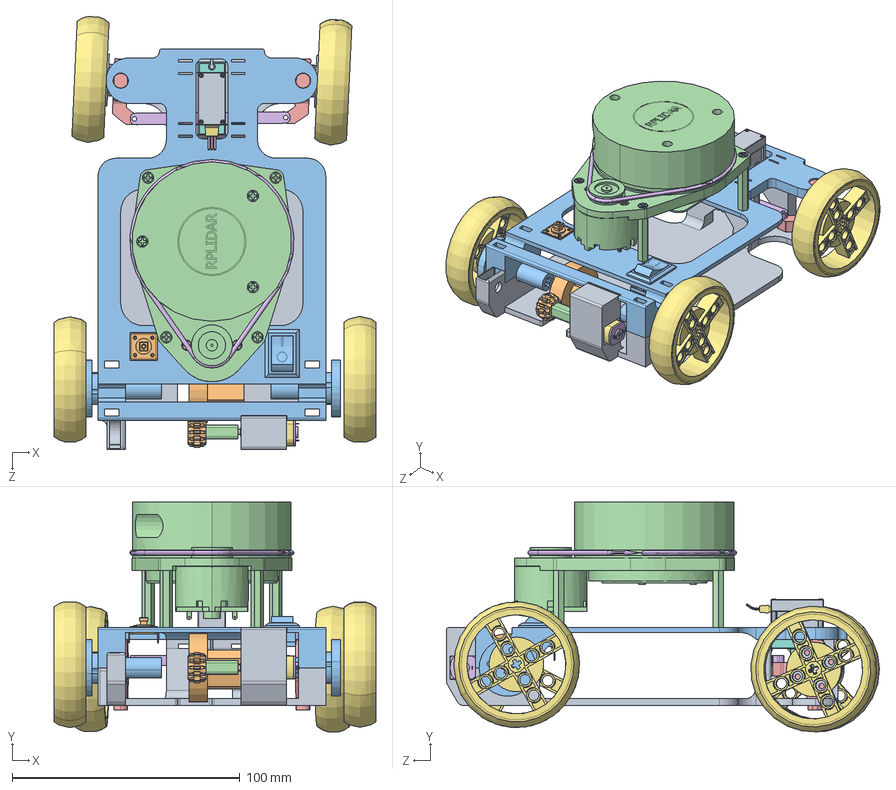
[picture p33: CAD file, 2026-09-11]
01_models/Full_Assy_Wro.STEP
141.2 x 100.8 x 190.0 mm
Main_chassis
Lego_12_tooth_gear
Long_shaft
Pololu
Top_cover
Motor_adapter
Free_wheel x 2
Steering_bar
Spike Rubber Wheel x 4
Eje_default_Peça x 2
Front_short_shaft x 2
Fake_diff_Predeterminado
Long_shaft_left
Lidar A1M8_Predeterminado
=___0 B0_B_20O2_По умолчанию
Switch

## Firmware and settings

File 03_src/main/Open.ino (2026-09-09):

#define lidarDebugSerial Serial
#include "thijs_rplidar.h"
#include <stdio.h>
#include <Arduino.h>
#include <Wire.h>
#include <math.h>
#include <esp_system.h>
#if !defined(ARDUINO_USB_CDC_ON_BOOT) || !ARDUINO_USB_CDC_ON_BOOT
#error "Activa USB CDC On Boot: Enabled para separar USB de UART0."
#endif
struct DistanceReading {
  uint16_t mm;
  uint32_t lastValidMs;
};
struct OpeningReading {
  uint16_t mm;
  uint32_t receivedMs;
  bool received;
};
enum TrackDirection { UNKNOWN, CCW, CW };
enum FirstWall { FIRST_NONE, FIRST_LEFT, FIRST_RIGHT };
enum TurnState { 
  NO_TURN, 
  TURNING_LEFT, TURNING_RIGHT 
};
enum RunState { RUNNING_LAPS, FINAL_APPROACH, FINISHED };

// Tramas @tipo,sesion,solicitud,arranque,dato*CRC16\n.
// CRC detecta corrupcion accidental; no es autenticacion criptografica.
#include <stdint.h>
#include <stdio.h>
#include <string.h>
struct CamFrame { char type; uint32_t session, id, boot; char data; };
inline uint16_t camCRC(const char *s, size_t n) {
  uint16_t crc=0xFFFF;
  for(size_t i=0;i<n;i++) {
    crc ^= (uint16_t)(uint8_t)s[i]<<8;
    for(int b=0;b<8;b++) crc=(crc&0x8000)?(uint16_t)((crc<<1)^0x1021):(uint16_t)(crc<<1);
  }
  return crc;
}
inline bool camHex(const char *s,int n,uint32_t &v) {
  v=0;
  for(int i=0;i<n;i++) {
    int d=s[i]>='0'&&s[i]<='9'?s[i]-'0':s[i]>='A'&&s[i]<='F'?s[i]-'A'+10:-1;
    if(d<0)return false;
    v=(v<<4)|(unsigned)d;
  }
  return true;
}
inline bool camParse(const char *s,CamFrame &f) {
  if(strlen(s)!=36 || s[0]!='@' || s[2]!=',' || s[11]!=',' || s[20]!=',' || s[29]!=',' || s[31]!='*')return false;
  uint32_t crc;
  if(!camHex(s+3,8,f.session)||!camHex(s+12,8,f.id)||!camHex(s+21,8,f.boot)||!camHex(s+32,4,crc))return false;
  if(camCRC(s+1,30)!=crc)return false;
  f.type=s[1];f.data=s[30];return true;
}
template<class Port> inline void camSend(Port &p,char type,uint32_t session,uint32_t id,uint32_t boot,char data) {
  char body[40],line[48];
  snprintf(body,sizeof(body),"%c,%08lX,%08lX,%08lX,%c",type,(unsigned long)session,(unsigned long)id,(unsigned long)boot,data);
  snprintf(line,sizeof(line),"@%s*%04X\n",body,(unsigned)camCRC(body,strlen(body)));
  p.print(line);
}
// Un @ nuevo resincroniza incluso si se perdio un salto de linea.
struct CamReader {
  char line[48]={}; size_t used=0; bool active=false; uint32_t bad=0;
  bool push(char c,CamFrame &f) {
    if(c=='@'){used=0;active=true;line[used++]=c;return false;}
    if(!active)return false;
    if(c=='\r')return false;
    if(c=='\n'){
      line[used]=0;active=false;
      if(camParse(line,f))return true;
      ++bad;return false;
    }
    if(used>=sizeof(line)-1){active=false;++bad;return false;}
    line[used++]=c;return false;
  }
};



// Tipos antes de cualquier funcion: compatibles con los prototipos de Arduino.








// UART0 libre porque Serial usa USB; Serial1 sigue siendo exclusivamente LiDAR.
static const int START_RX_PIN=17, START_TX_PIN=21;
static bool robotStarted=false;
static bool motionEnabled=false;
static uint32_t startAcceptedMs=0;
static const uint32_t START_DELAY_MS=500;
static uint32_t startSession=0, startCameraBoot=0, lastStartHello=0;
static CamReader startReader;
void setupStartLink() {
  startSession=esp_random(); if(!startSession)startSession=1;
  camSend(Serial0,'T',startSession,1,0,'?');
  lastStartHello=millis();
  Serial.println("[ARRANQUE] Sensores preparados. Esperando enlace con la camara...");
}
void pollStartLink() {
  CamFrame f; int budget=128;
  while(Serial0.available() && budget-->0) {
    if(!startReader.push((char)Serial0.read(),f) || f.session!=startSession)continue;
    if(f.type=='U' && f.id==1 && f.data=='R' && f.boot) {
      if(!robotStarted && startCameraBoot!=f.boot)
        Serial.println("[ARRANQUE] LISTO: pulsa y suelta el boton de la camara.");
      startCameraBoot=f.boot;
    } else if(f.type=='D' && !robotStarted && f.boot==startCameraBoot && startCameraBoot &&
              (f.data=='0' || f.data=='1')) {
      Serial.print("[BOTON CAM IO15] ");
      Serial.print(f.data=='0' ? "LOW/presionado" : "HIGH/suelto");
      Serial.print(" | estable="); Serial.print((f.id&1)?"HIGH":"LOW");
      Serial.print(" | habilitado="); Serial.print((f.id&2)?"SI":"NO");
      Serial.print(" | orden pendiente="); Serial.println((f.id&4)?"SI":"NO");
    } else if(f.type=='S' && (f.data=='0' || f.data=='1') && f.id && f.boot==startCameraBoot && startCameraBoot) {
      camSend(Serial0,'K',f.session,f.id,f.boot,'K');
      if(!robotStarted) {
        robotStarted=true;
        startAcceptedMs=millis();
        Serial.println("[ARRANQUE] Boton recibido. Esperando 500 ms.");
      }
    }
  }
  if(!robotStarted && millis()-lastStartHello>=500) {
    lastStartHello=millis();camSend(Serial0,'T',startSession,1,0,'?');
  }
}

// XIAO ESP32-C6
static const int SDA_PIN = 18; // D10
static const int SCL_PIN = 1;  // D1

// Cambia a -1.0f si deseas invertir el sentido del yaw.
// Convencion del control: derecha/CW positivo. Verificar con el sensor montado.
static const float YAW_SIGN = -1.0f;

// Giroscopio configurado a +/-500 grados/segundo.
static const float GYRO_SCALE = 65.6f;
// 500 muestras a 100 Hz: unos 5 s de calibracion si esta quieto.
// Tras preparar los sensores, esperar una pulsacion nueva del boton.
static const int IMU_CALIBRATION_SAMPLES = 500;

uint8_t bmiAddress = 0;
float biasZ = 0.0f;
float yaw = 0.0f;
float velocidadZ = 0.0f;

uint32_t ultimaMuestraUs = 0;
uint32_t ultimaImpresionMs = 0;
bool yawValido = true;
const char *imuInvalidReason = "NINGUNO";

bool leerRegistros(uint8_t reg, uint8_t *datos, size_t n) {
  Wire.beginTransmission(bmiAddress);
  Wire.write(reg);

  if (Wire.endTransmission(false) != 0) {
    return false;
  }

  size_t recibidos = Wire.requestFrom(bmiAddress, n);

  if (recibidos != n) {
    while (Wire.available()) Wire.read();
    return false;
  }

  for (size_t i = 0; i < n; i++) {
    datos[i] = Wire.read();
  }

  return true;
}

bool escribirRegistro(uint8_t reg, uint8_t valor) {
  Wire.beginTransmission(bmiAddress);
  Wire.write(reg);
  Wire.write(valor);
  return Wire.endTransmission() == 0;
}

void detenerPorError(const char *mensaje) {
  Serial.print("ERROR: ");
  Serial.println(mensaje);

  while (true) {
    delay(1000);
  }
}

bool buscarBMI160() {
  const uint8_t direcciones[] = {0x68, 0x69};

  for (uint8_t direccion : direcciones) {
    bmiAddress = direccion;

    uint8_t chipID = 0;

    if (leerRegistros(0x00, &chipID, 1) && chipID == 0xD1) {
      return true;
    }
  }

  return false;
}

// Devuelve:
//  1: muestra nueva
//  0: todavia no hay muestra nueva
// -1: error I2C
int leerGiroscopio(float &gx, float &gy, float &gz) {
  uint8_t estado;

  if (!leerRegistros(0x1B, &estado, 1)) {
    return -1;
  }

  // STATUS bit 6: datos nuevos del giroscopio.
  if (!(estado & 0x40)) {
    return 0;
  }

  uint8_t datos[6];

  if (!leerRegistros(0x0C, datos, sizeof(datos))) {
    return -1;
  }

  int16_t rawX = (int16_t)(
    (uint16_t)datos[0] | ((uint16_t)datos[1] << 8)
  );

  int16_t rawY = (int16_t)(
    (uint16_t)datos[2] | ((uint16_t)datos[3] << 8)
  );

  int16_t rawZ = (int16_t)(
    (uint16_t)datos[4] | ((uint16_t)datos[5] << 8)
  );

  gx = rawX / GYRO_SCALE;
  gy = rawY / GYRO_SCALE;
  gz = rawZ / GYRO_SCALE;

  return 1;
}

void calibrar() {
  Serial.println("Deja el sensor horizontal y completamente quieto.");
  Serial.println("Preparando calibracion...");
  // La inicializacion del sensor ya dio tiempo de asentamiento.

  // Descartar una muestra anterior a la calibracion.
  float gx, gy, gz;
  leerGiroscopio(gx, gy, gz);

  const int TOTAL = IMU_CALIBRATION_SAMPLES;
  int muestras = 0;

  double sumaZ = 0;
  float minimoZ = 10000;
  float maximoZ = -10000;

  uint32_t inicio = millis();
  bool avisoMovimiento = false;

  while (muestras < TOTAL) {
    int estado = leerGiroscopio(gx, gy, gz);

    if (estado < 0) {
      detenerPorError("Fallo I2C durante la calibracion.");
    }

    if (estado == 1) {
      // Rechazar movimientos evidentes.
      if (fabsf(gx) > 5.0f ||
          fabsf(gy) > 5.0f ||
          fabsf(gz) > 5.0f) {
        muestras = 0; sumaZ = 0; minimoZ = 10000; maximoZ = -10000;
        if (!avisoMovimiento) Serial.println("Movimiento: repitiendo calibracion automaticamente.");
        avisoMovimiento = true;
      } else {
        float nuevoMin = gz < minimoZ ? gz : minimoZ;
        float nuevoMax = gz > maximoZ ? gz : maximoZ;
        if (nuevoMax - nuevoMin > 2.0f) {
          // Empezar otra ventana, sin exigir reiniciar la placa.
          muestras = 1; sumaZ = gz; minimoZ = maximoZ = gz;
        } else {
          sumaZ += gz; minimoZ = nuevoMin; maximoZ = nuevoMax; muestras++;
        }
      }
    }

    if (millis() - inicio > 8000) {
      yawValido = false;
      imuInvalidReason = "CALIBRACION";
      ultimaMuestraUs = 0;
      Serial.println("Sin calibracion estable: arrancando con control LiDAR, sin IMU hasta reiniciar.");
      return;
    }

    delay(1);
  }

  biasZ = sumaZ / TOTAL;
  yaw = 0;
  ultimaMuestraUs = 0;
  yawValido = true;
  imuInvalidReason = "NINGUNO";

  Serial.print("Calibrado. Offset Z: ");
  Serial.print(biasZ, 4);
  Serial.println(" grados/s");
  Serial.println("IMU lista. Referencia inicial establecida.");
}

void imuSetup() {
  Serial.begin(115200);

  // El arranque de pista no depende de que una computadora abra el USB.

  Wire.begin(SDA_PIN, SCL_PIN);
  Wire.setClock(100000);
  Wire.setTimeOut(5);

  delay(100);

  if (!buscarBMI160()) {
    detenerPorError(
      "BMI160 no encontrado en 0x68/0x69. Revisa conexiones."
    );
  }

  Serial.print("BMI160 encontrado en 0x");
  Serial.println(bmiAddress, HEX);

  // Reset del sensor.
  if (!escribirRegistro(0x7E, 0xB6)) {
    detenerPorError("No se pudo reiniciar el BMI160.");
  }

  delay(100);

  // Giroscopio en modo normal.
  if (!escribirRegistro(0x7E, 0x15)) {
    detenerPorError("No se pudo activar el giroscopio.");
  }

  delay(100);

  // 100 Hz, filtrado normal.
  if (!escribirRegistro(0x42, 0x28) ||
      !escribirRegistro(0x43, 0x02)) {
    detenerPorError("No se pudo configurar el giroscopio.");
  }

  delay(100);

  uint8_t configuracion, rango, modo;

  if (!leerRegistros(0x42, &configuracion, 1) ||
      !leerRegistros(0x43, &rango, 1) ||
      !leerRegistros(0x03, &modo, 1) ||
      configuracion != 0x28 ||
      (rango & 0x07) != 0x02 ||
      (modo & 0x0C) != 0x04) {
    detenerPorError("La configuracion del BMI160 no se confirmo.");
  }

  calibrar();
}

void imuUpdate() {
  static uint32_t lastPollUs = 0;
  uint32_t pollUs = micros();
  if (pollUs - lastPollUs < 5000) return;
  lastPollUs = pollUs;
  float gx, gy, gz;
  int estado = leerGiroscopio(gx, gy, gz);
  uint32_t ahoraUs = micros();

  if (estado < 0) {
    if (yawValido) {
      Serial.println("ERROR I2C: control LiDAR de respaldo hasta reiniciar.");
    }

    yawValido = false;
    imuInvalidReason = "I2C";
    ultimaMuestraUs = 0;
  }

  if (estado == 1) {
    velocidadZ = (gz - biasZ) * YAW_SIGN;

    if (ultimaMuestraUs != 0) {
      uint32_t intervaloUs = ahoraUs - ultimaMuestraUs;

      // No fingir continuidad si hubo un hueco grande de lecturas.
      if (intervaloUs > 50000) {
        yawValido = false;
        imuInvalidReason = "HUECO_MUESTRAS_50MS";
      } else if (yawValido) {
        float dt = intervaloUs * 0.000001f;
        yaw += velocidadZ * dt;

        // Salida entre -180 y +180 grados.
        while (yaw >= 180.0f) yaw -= 360.0f;
        while (yaw < -180.0f) yaw += 360.0f;
      }
    }

    ultimaMuestraUs = ahoraUs;
  }

  if (ultimaMuestraUs != 0 &&
      (uint32_t)(ahoraUs - ultimaMuestraUs) > 100000) {
    yawValido = false;
    imuInvalidReason = "SIN_MUESTRAS_100MS";
  }

}


// Solo observacion: no cambia las decisiones de navegacion.
static const bool DEBUG_CURVAS_CW = true;
static const uint32_t DEBUG_CURVAS_INTERVAL_MS = 500;


// Ajustes iniciales para pista. Yaw y objetivos: CW positivo, CCW negativo.
static const float KP_DISTANCE_YAW = 0.025f; // grados por mm de error de rayo
static const float MAX_DISTANCE_YAW = 8.0f;
static const float KP_YAW = 1.5f;            // grados de servo / grado de yaw
static const float KD_YAW_RATE = 0.12f;      // amortiguacion por grados/s
static const float DISTANCE_SLEW_DPS = 12.0f;
static const float TURN_YAW_TOL_DEG = 4.0f;
static const float TURN_RATE_TOL_DPS = 35.0f;
static const uint32_t TURN_SETTLE_MS = 60;
static const float DRIFT_MAX_DPS = 0.5f;
static const float DRIFT_TIME_CONSTANT_S = 8.0f;
static const uint32_t WALL_PAIR_MAX_AGE_MS = 250;
static const uint32_t WALL_PAIR_MAX_SKEW_MS = 80;
float corridorYaw = 0, yawOffset = 0, distanceYaw = 0;
float commandedYaw = 0;
uint32_t turnSettledSince = 0;
bool imuTurnActive = false;
bool driftReferenceOK = false;
float wrapYaw(float x) {
  while (x >= 180) x -= 360;
  while (x < -180) x += 360;
  return x;
}
float clampValue(float x,float lo,float hi) { return x < lo ? lo : x > hi ? hi : x; }
float correctedYaw() { return wrapYaw(yaw + yawOffset); }

// --- Pines ESP32-C6 ---
#define LIDAR_RX_PIN 19  
#define LIDAR_TX_PIN 16  
#define MOTOR_PIN    20  
#define SERVO_PIN     0  

// --- TB6612FNG: motor de avance ---
#define PWMA 22
#define AIN1 23
#define AIN2 2

// ==========================================
// --- CONSTANTES DE DETECCIÓN DE CURVA ---
// ==========================================
#define FRONT_TURN_DISTANCE_MM 1200 
#define LOOK_OPEN_DISTANCE_MM 1200
#define LOOK_OPEN_CONFIRM_MS 100
#define SIDE_WALL_CLOSED_MM 900   
#define LOOK_WALL_CLOSED_MM 1200  
#define BACK_CLEAR_DISTANCE_MM 1500

#define PARALLEL_TOLERANCE_MM 60 
#define MAX_TURN_TIMEOUT_MS 1400 // Ampliado ligeramente para evitar salidas forzadas prematuras en CW
#define NEW_HALLWAY_CLEAR_MM 1500

// Setpoint Acotado (Clamping)
#define SETPOINT_MIN_MM 325
#define SETPOINT_MAX_MM 375
// ==========================================

// --- Otras Configuraciones ---
#define TOLERANCE_DEG 2 // Estrechado a 2° para eliminar el sesgo de barrido del LiDAR
#define SIDE_PID_TOLERANCE_DEG 10
#define MAX_DISTANCE_MM 6000
#define HOLD_LAST_VALID_MS 300
#define PRINT_INTERVAL_MS 50
#define PID_INTERVAL_MS 20 
#define PID_MAX_VALID_DISTANCE_MM 1000
#define PID_STALE_MS 250

// Velocidades dinámicas
#define DRIVE_PWM_NORMAL 255
#define DRIVE_PWM_SLOW   255


// --- FIN DE RECORRIDO: circuito de 4 curvas por vuelta ---
#define LAPS_TO_COMPLETE 3
#define CORNERS_PER_LAP 4
// Ajustar en pista: tiempo desde la salida de curva 12 hasta la zona inicial.
// 1000 ms es SOLO un valor inicial de calibracion; no localiza el inicio.
#define FINAL_APPROACH_MS 800UL
#define FINAL_APPROACH_PWM DRIVE_PWM_NORMAL

// --- CONSTANTES PID HÍBRIDO ---
#define KP_POS       0.05f 
// Ganancias de paralelismo editables segun el sentido detectado.
static const float KP_PARALLEL_FIRST = 2.5f; // Primer carril, sentido UNKNOWN
static const float KP_PARALLEL_CCW   = 2.5f; // Antihorario
static const float KP_PARALLEL_CW    = 2.5f; // Horario
#define KI           0.0f
#define KD           0.001f

#define SERVO_LEFT 60
#define SERVO_CENTER 90
#define SERVO_RIGHT 120

RPlidar lidar(Serial1);
bool lidarStarted = false;



// --- Cono frontal ---
DistanceReading frontReading = {0, 0};       
DistanceReading frontLeftReading = {0, 0};   
DistanceReading frontRightReading = {0, 0};  

// --- Cono trasero ---
DistanceReading backReading = {0, 0};        
DistanceReading back170Reading = {0, 0};     
DistanceReading back190Reading = {0, 0};     

// --- Laterales y Lookaheads ---
DistanceReading leftReading = {0, 0};        
DistanceReading leftLookReading = {0, 0};    // 300°
DistanceReading rightReading = {0, 0};       
DistanceReading rightLookReading = {0, 0};   // 60°   

// --- Lookaheads Traseros (Paralelismo simétrico exacto) ---
DistanceReading leftBackLookReading = {0, 0};  // 240° (Espejo perfecto de 120°)
DistanceReading rightBackLookReading = {0, 0}; // 120°

DistanceReading pidLeftReading = {0, 0};
DistanceReading pidRightReading = {0, 0};

float pidIntegral = 0.0f;
float pidLastError = 0.0f;
float smoothedError = 0.0f; // Global para evitar arrastrar residuos de la curva
uint32_t pidLastMs = 0;

int servoPosition = SERVO_CENTER;

// --- SETPOINT DINÁMICO ACOTADO ---
float targetWallDistance = 375.0f; 

// --- ESTADOS DE PISTA ---

TrackDirection trackDir = UNKNOWN;

// Solo primer carril: referencia independiente del setpoint de las curvas.

FirstWall firstWall = FIRST_NONE;
float firstWallTarget = 0.0f;
DistanceReading firstLeftFront = {0, 0};   // 300 grados
DistanceReading firstLeftBack = {0, 0};    // 240 grados
DistanceReading firstRightFront = {0, 0};  // 60 grados
DistanceReading firstRightBack = {0, 0};   // 120 grados


// --- MÁQUINA DE ESTADOS ---

TurnState turnState = NO_TURN;

uint32_t turnStartTime = 0;


RunState runState = RUNNING_LAPS;
uint16_t completedCorners = 0;
uint32_t finalApproachStartMs = 0;
// Requerir que la apertura anterior se cierre antes de armar otra curva.
bool cornerRearmPending = false;

bool leftLookSawWall = false;
bool rightLookSawWall = false;
uint32_t leftOpenSinceMs = 0;
uint32_t rightOpenSinceMs = 0;

bool angleMatches(float angle, float target) {
  float difference = angle - target;
  if (difference > 180.0f) difference -= 360.0f;
  if (difference < -180.0f) difference += 360.0f;
  return (difference >= -TOLERANCE_DEG && difference <= TOLERANCE_DEG);
}

bool angleMatchesSidePID(float angle, float target) {
  float difference = angle - target;
  if (difference > 180.0f) difference -= 360.0f;
  if (difference < -180.0f) difference += 360.0f;
  return (difference >= -SIDE_PID_TOLERANCE_DEG &&
          difference <= SIDE_PID_TOLERANCE_DEG);
}

void saveReading(DistanceReading &reading, uint16_t distance) {
  reading.mm = distance;
  reading.lastValidMs = millis();
}


// Prototipos explicitos: Arduino no debe generarlos antes de este struct.
bool openingFresh(const OpeningReading &r);
bool openingDetected(const OpeningReading &r);
bool openingWall(const OpeningReading &r);

OpeningReading leftOpening = {0, 0, false};
OpeningReading rightOpening = {0, 0, false};

bool openingFresh(const OpeningReading &r) {
  return r.received && millis() - r.receivedMs <= HOLD_LAST_VALID_MS;
}
bool openingDetected(const OpeningReading &r) {
  return openingFresh(r) && (r.mm == 0 || r.mm >= LOOK_OPEN_DISTANCE_MM);
}
bool openingWall(const OpeningReading &r) {
  return openingFresh(r) && r.mm > 0 && r.mm < LOOK_OPEN_DISTANCE_MM;
}
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
void loop() {
  imuUpdate();
  static uint32_t sensorReportMs=0;
  if(firstWall==FIRST_NONE && millis()-sensorReportMs>=1000) {
    sensorReportMs=millis();
    Serial.print("[SENSORES] puntosLidar=");Serial.print(lidarPointCount);
    Serial.print(" | edadUltimoPunto=");Serial.print(millis()-lidarLastPointMs);
    Serial.print(" | IMU=");Serial.print(yawValido?"OK":"INVALIDA");
    Serial.print(" | motivo=");Serial.println(imuInvalidReason);
  }
  pollStartLink();
  if(!robotStarted || millis()-startAcceptedMs<START_DELAY_MS) {
    if(lidarStarted) lidar.handleData(true,false);
    else {
      static uint32_t retry=0;
      if(millis()-retry>=1000){retry=millis();startLidar();}
    }
    return;
  }
  if(!motionEnabled) {
    motionEnabled=true;
    Serial.println("[ARRANQUE] Espera terminada. Iniciando recorrido.");
    // Inicio desde la orientacion en que el usuario coloco el robot.
    // No convertir una IMU invalida en valida por recibir el boton.
    yaw=0; yawOffset=0; corridorYaw=0; commandedYaw=0; distanceYaw=0;
    ultimaMuestraUs=0; pidLastMs=millis();
    firstWall=FIRST_NONE; firstWallTarget=0;
    driveForward(DRIVE_PWM_NORMAL);
  }
  updateRunCompletion();
  if (runState == FINISHED) return;
  if (lidarStarted) {
    lidar.handleData(true, false);
  } else {
    static uint32_t lastRetryMs = 0;
    if (millis() - lastRetryMs >= 1000) {
      lastRetryMs = millis();
      startLidar();
      if (lidarStarted) {
         if (turnState == NO_TURN) driveForward(DRIVE_PWM_NORMAL);
         else driveForward(DRIVE_PWM_SLOW); 
      }
    }
  }

  updateRunCompletion();
  if (runState == FINISHED) return;
  updateSteeringPID();
  checkForTurn();
  diagnosticarCurvasCW();
}

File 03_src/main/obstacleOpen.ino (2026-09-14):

/* Obstacle Challenge - CW-CARRIL2
   Esquina referida a pared, reversa con IMU, parada por hueco de carroceria.
   Arranque con tres fotos vacias validas y paredes; primera evasion gradual.
   Conserva PWM 150, direccion +/-40, minimo 60 mm y admision 350-1000 mm.
   Paredes: dos medidas o una medida + ancho reciente; sin eco, breve rumbo recto.
   Datos perdidos: ESPERA_DATOS sin traccion y recuperacion verificada.
   No recupera yaw invalido ni ignora peligros confirmados. Centrado sin limite de 12 s.
   MOVING anticipa fotos al enderezar; LIBRE exige que la parte trasera haya pasado.
*/
#include <Arduino.h>
#include <esp_system.h>
#include <Wire.h>
#include <math.h>
#define lidarDebugSerial Serial
#include "thijs_rplidar.h"
#if !defined(ARDUINO_USB_CDC_ON_BOOT) || !ARDUINO_USB_CDC_ON_BOOT
#error "Activa USB CDC On Boot: Enabled en la C6."
#endif
// Tramas @tipo,sesion,solicitud,arranque,dato*CRC16\n.
// CRC detecta corrupcion accidental; no es autenticacion criptografica.
#include <stdint.h>
#include <stdio.h>
#include <string.h>

// Definir el tipo antes de cualquier funcion: Arduino puede insertar aqui
// prototipos automaticos de funciones declaradas mucho mas abajo.
struct ApproachWall {
  bool valid=false;
  float gap=0, normalAngle=0, yawAtFit=0, span=0;
  bool held=false;
  uint32_t stamp=0, age=0;
  unsigned count=0;
};
ApproachWall measureApproachWall();
ApproachWall fitCornerWall(bool rear,uint32_t minimumAge=0);
ApproachWall cornerWallReading(bool rear);
void clearCornerTracker();
float estimatedWallGap(const ApproachWall &wall);
bool finishKnownPassedPillar();

// --- ESTADOS ACTUALIZADOS ---
enum MotionState { WAIT_PILLAR, MOVING, PARALLEL, DECIDE_NEXT, CENTERING, CORNER_HOLD, RECOVERING, DONE, FAULT, APPROACHING_FRONT, REVERSING_TURN, REVERSING_STRAIGHT, FINISHED_SEQ, WAIT_BEFORE_REVERSE, PREPARE_SECOND_LANE };
enum RecoveryCause { RX_MISSING, PILLAR_MISSING, VISION_MISSING, WALLS_MISSING };
void pauseMotion(RecoveryCause cause,const char *reason);
bool centerReference(float &error,bool &oneWall);
void enterCentering();
void serviceRecovery();
struct PillarReading {
  bool valid=false; float x=0,y=0,distance=0,bearing=0;
  float minX=0,maxX=0,minY=0,maxY=0;
  uint32_t stamp=0; unsigned count=0;
};
// Prototipos explicitos: evitar que Arduino los coloque antes del tipo.
PillarReading findPillar(float center,float halfWindow,bool tracking,const PillarReading *reference=nullptr);
bool distinctFromCurrent(const PillarReading &c);
bool nextReady();
void beginManeuver();
bool viewAdjustmentAllowed();
struct TrackDiagnostic {
  unsigned returns=0,groups=0,shape=0,time=0,association=0,accepted=0;
  unsigned edge=0,narrow=0,wide=0,sparse=0;
  float halfWindow=0;
};
struct FrontDiagnostic {
  unsigned count=0;float distance=0,angle=0,x=0,y=0;uint32_t age=0;
};
// --- Deteccion de fin de carril / esquina CW ---------------------------
struct CornerEvidence {
  bool frontWall=false, rightOpen=false, leftWall=false, cameraAgrees=false;
  float frontDistanceMM=0, frontSpanMM=0, leftWallMM=0, rightWallMM=0;
  unsigned frontCount=0; uint32_t frontAge=0;
};
bool frontWallEvidence(CornerEvidence &ev);
bool sampleCornerEvidence(CornerEvidence &ev);
bool checkCornerCW();
void printCornerDiagnostic();
void holdCorner();
void handleCornerHold();

struct LidarStreamReader {
  uint8_t bytes[15]={};unsigned used=0;
  uint32_t discarded=0,packets=0,headerRejects=0,angleRejects=0;
  static uint16_t angle(const uint8_t *p){return ((uint16_t)p[2]<<7)|(p[1]>>1);}
  static bool valid(const uint8_t *p){
    unsigned flags=p[0]&3;
    return (flags==1 || flags==2) && (p[1]&1) && angle(p)<360*64;
  }
  static bool follows(const uint8_t *a,const uint8_t *b){
    int delta=(int)angle(b)-(int)angle(a);
    if(delta< -180*64)delta+=360*64;
    if(delta>180*64)delta-=360*64;
    return delta>=-2*64 && delta<=20*64;
  }
  bool push(uint8_t b,uint16_t &distance,uint16_t &angleQ6,uint8_t &start,int8_t &quality){
    bytes[used++]=b;
    if(used<sizeof(bytes))return false;
    bool headers=valid(bytes) && valid(bytes+5) && valid(bytes+10);
    bool angles=headers && follows(bytes,bytes+5) && follows(bytes+5,bytes+10);
    bool good=headers && angles;
    if(good){
      distance=(((uint16_t)bytes[4]<<8)|bytes[3])>>2;
      angleQ6=angle(bytes);start=(bytes[0]&3)==1;quality=bytes[0]>>2;
      memmove(bytes,bytes+5,10);used=10;++packets;return true;
    }
    if(!headers)++headerRejects;else ++angleRejects;
    memmove(bytes,bytes+1,14);used=14;++discarded;return false;
  }
  void reset(){used=0;}
};
struct CamFrame { char type; uint32_t session, id, boot; char data; };
inline uint16_t camCRC(const char *s, size_t n) {
  uint16_t crc=0xFFFF;
  for(size_t i=0;i<n;i++) {
    crc ^= (uint16_t)(uint8_t)s[i]<<8;
    for(int b=0;b<8;b++) crc=(crc&0x8000)?(uint16_t)((crc<<1)^0x1021):(uint16_t)(crc<<1);
  }
  return crc;
}
inline bool camHex(const char *s,int n,uint32_t &v) {
  v=0;
  for(int i=0;i<n;i++) {
    int d=s[i]>='0'&&s[i]<='9'?s[i]-'0':s[i]>='A'&&s[i]<='F'?s[i]-'A'+10:-1;
    if(d<0)return false;
    v=(v<<4)|(unsigned)d;
  }
  return true;
}
inline bool camParse(const char *s,CamFrame &f) {
  if(strlen(s)!=36 || s[0]!='@' || s[2]!=',' || s[11]!=',' || s[20]!=',' || s[29]!=',' || s[31]!='*')return false;
  uint32_t crc;
  if(!camHex(s+3,8,f.session)||!camHex(s+12,8,f.id)||!camHex(s+21,8,f.boot)||!camHex(s+32,4,crc))return false;
  if(camCRC(s+1,30)!=crc)return false;
  f.type=s[1];f.data=s[30];return true;
}
template<class Port> inline void camSend(Port &p,char type,uint32_t session,uint32_t id,uint32_t boot,char data) {
  char body[40],line[48];
  snprintf(body,sizeof(body),"%c,%08lX,%08lX,%08lX,%c",type,(unsigned long)session,(unsigned long)id,(unsigned long)boot,data);
  snprintf(line,sizeof(line),"@%s*%04X\n",body,(unsigned)camCRC(body,strlen(body)));
  p.print(line);
}
struct CamReader {
  char line[48]={}; size_t used=0; bool active=false; uint32_t bad=0;
  bool push(char c,CamFrame &f) {
    if(c=='@'){used=0;active=true;line[used++]=c;return false;}
    if(!active)return false;
    if(c=='\r')return false;
    if(c=='\n'){
      line[used]=0;active=false;
      if(camParse(line,f))return true;
      ++bad;return false;
    }
    if(used>=sizeof(line)-1){active=false;++bad;return false;}
    line[used++]=c;return false;
  }
};

static const int SDA_PIN = 18; // D10
static const int SCL_PIN = 1;  // D1
static const float YAW_SIGN = -1.0f;
static const float GYRO_SCALE = 65.6f;
static const int IMU_CALIBRATION_SAMPLES = 500;

uint8_t bmiAddress = 0;
float biasZ = 0.0f;
float yaw = 0.0f;
float velocidadZ = 0.0f;

uint32_t ultimaMuestraUs = 0;
uint32_t ultimaImpresionMs = 0;
bool yawValido = true;
const char *imuInvalidReason = "NINGUNO";
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

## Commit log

2026-09-11 Added CAD
    [Full_Assy_Wro.STEP]
2026-09-11 Create LiPo 7.4V 800Mah.jpg
2026-09-11 Document mechanical design process in README
    Added detailed mechanical design process including chassis, steering system, drivetrain, and sensor integration sections.
2026-09-12 V photos chassis
2026-09-12 Added CAD images
2026-09-12 Refine wording in README for chassis description
    Corrected wording for clarity and consistency in the chassis section.
2026-09-12 Clarify design choice for Power Transfer section
    Added reasoning for choosing a LEGO build design over a 3D printed one in the Power Transfer section.
2026-09-12 Update Ackermann steering mechanism description
    Revised description of the Ackermann steering mechanism for clarity and efficiency.
2026-09-12 Update camera mount description in README
    Clarified the description of the camera mount for better readability.
2026-09-12 Update IMU Sensor description to BMI160
2026-09-13 Fix motor type and spelling in README
    Corrected motor description and spelling errors in the drivetrain section.
2026-09-13 Add emoji to Wiring Diagram section in README
2026-09-13 Organize project assets into numbered folders
    Reorganized the repository by moving project assets into numbered folders for better structure and consistency. This includes the CAD model, electrical scheme, source files, photos, video, and append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
    [Full_Assy_Wro.STEP]
2026-09-13 Refactor README for image paths and assembly steps
    Updated image paths and added additional details for assembly and wiring instructions.
2026-09-13 Fix image paths in README.md
    Updated image paths in the README for top and chassis.
2026-09-13 Add electronic diagram; rename scheme image
    Adds 02_schemes/Electronic_diagram.png and renames 02_schemes/Electronic_Scheme.jpg to 02_schemes/Wiring_diagram.jpg (100% similarity — content unchanged). This clarifies the wiring/scheme filenames.
2026-09-13 Enhance README with image and chassis information
    Added an image to the mechanical design section and expanded on chassis details.
2026-09-13 Specify CAD software used in mechanical design
    Added mention of SolidWorks as the CAD software used for design.
2026-09-13 Enhance README with detailed design explanations
    Expanded explanations for steering and drivetrain sections, detailing the transition from parallel to Ackermann steering and improvements in power transfer design. Clarified sensor integration challe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
2026-09-13 Enhance README with CAD and final build images
    Added CAD and final build images to the README for better visualization of the drivetrain and transmission.
2026-09-13 Enhance README with mounting holes table and details
    Added a table for mounting holes and improved descriptions for sensor integration.
2026-09-13 Adjust image size in README for mounting holes section
    Reduced image width for better layout in README.
2026-09-13 Rename blank top-view asset
    This commit renames the appendix image from blank_topview.png to blank_top_view.png for consistency with the project’s naming conventions. No content changes are included; this is a metadata/file-nam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
2026-09-13 Adjust image width for camera mount section
    Added width attribute to the camera mount image for better display.
2026-09-13 Update image dimensions for steering diagrams
    Adjusted image sizes for steering diagrams in README.
2026-09-14 Update README with image limitations explanation
    Added note about image limitations due to lidar functionality.
2026-09-14 Add Transmission & Gear Ratio section to README
    Added a new section on Transmission & Gear Ratio detailing specifications and performance choices.
2026-09-14 Update key torque and performance choices section
2026-09-14 Add ESP32-CAM camera & detector code
    Add complete ESP32-CAM (AI Thinker + OV2640) implementation: main sketch (03_src/camera/Camara_ESP32.ino) with UART robot protocol, start-button logic, photo capture, JPEG decoding, caching and webse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
